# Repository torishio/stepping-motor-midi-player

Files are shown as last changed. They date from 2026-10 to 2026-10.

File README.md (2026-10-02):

# ステッピングモータでMIDIを再生できるやつ

stepping-motor-midi-player

USB MIDIで受け取った音を、ステッピングモーターに実際に鳴かせて音にするMIDIシンセサイザー。

**Languages:** [日本語](#日本語) | [English](#english) | [中文](#中文) | [한국어](#한국어)

---

## 日本語

### これは何?

STEPピンをMIDIノートの音程とぴったり同じ周波数でパカパカ切り替えると、ステッピングモーターがその音程で鳴いてくれる(singing stepperってやつ)。この現象を使って、A4988ドライバ+モーター1組を1音分の音源として、DAWやシーケンサーからMIDIで弾けるようにしたもの。各チャンネルにArduinoを1枚使うので、マスター機とかは無し。全部のArduinoが個別にUSB MIDI機器として認識される。

### 中身

- **`firmware/`** — Arduino(Pro Micro互換ボード)に書き込むスケッチ。
  - `stp_motr_channel_velocity/` → こっちが最終版。音程だけじゃなくベロシティ(強弱)もマイクロステップの粗さで表現できる。
  - `stp_motr_channel/` → ベロシティは見てない、シンプルな方。
  - 全チャンネル、同じスケッチを書き込むだけでOK。
- **`hardware/`** — 本番基板(2ch、100×50mm)関連を全部入れてある。
  - **`stp-motr-2ch-100x50-gerbers.zip`** → 製造用データ一式。KiCadすら開かずに、これをJLCPCBとかにそのままアップロードすれば発注できる。
  - `gerbers/` → 上のZIPを展開したやつ。個別に見たい時用。
  - `stp-motr-2ch-100x50.kicad_pro` / `.kicad_sch` / `.kicad_pcb` → 編集・確認したい人向けのKiCadデータ。自作フットプリント/シンボルも `stp_motr.pretty/` `stp_motr.kicad_sym` に同封してるので、これだけで開ける。
  - **`BOM.csv`** → 部品リスト。
  - **`digikey_order.csv`** → Digikeyにそのままインポートできる注文リスト。

### Arduino⇔A4988の配線

1チャンネル分の結線はこんな感じ。他のチャンネルも同じ。

Arduino Pro MicroとA4988の配線図

- D4→STEP、D5→DIR、D6→EN(常時LOWでドライバON)
- A0→MS1、A1→MS2、A2→MS3(マイクロステップの切り替え)
- VCC→VDD、GND→GND
- A4988側のRSTとSLPは自分同士でジャンパーするだけ、Arduino側のピンは要らない
- VMOT・コイル出力(1A/1B/2A/2B)・外部+12Vは図から省略(モーター/電源側の配線なので)

### 専用基板を使わず自分で組む場合

基板を起こさずブレッドボードとかで直結したい人向けに、電源・コンデンサ・モーターまで全部含めた回路図も置いてある。

DIY配線の全体回路図

- Arduino側のピンは上と同じ(D4/D5/D6/A0/A1/A2/VCC/GND)
- VMOT-GND間に100&micro;F(低周波の電流供給用)と100nF(PWMノイズ吸収用)を並列で入れる — これが無いとモーターがガキゴカ鳴りやすい
- 外部電源は使うモーターの定格電圧に合わせる(12V用モーターなら12V)
- A4988の1A/1B/2A/2Bをモーターの4本のコイル線に(どっちが1A/1Bかは実際に回してみて逆なら入れ替えればOK)
- Arduino GND・A4988のGND(2本とも)・コンデンサのGND足・外部電源のGND(-)は全部同じ1本のグラウンドとしてつなぐ
- A4988基板上のトリマ(Vref)で電流制限を調整するのを忘れずに。Pololu版(Rsense=0.1&Omega;)なら **Vref=0.8Vで1A制限** になる感じがちょうどいい。ここを合わせないとモーターが熱くなりすぎたり、逆に力が出なかったりする

### 用意するもの

- Arduino Pro Micro互換ボード(ATmega32U4, 5V/16MHz)をチャンネル数分
- Pololu A4988(ヒートシンク付きがおすすめ)をチャンネル数分
- NEMA17クラスのステッピングモーターをチャンネル数分
- 細かい部品は `hardware/BOM.csv` 見てください

### 基板の発注

1. `hardware/stp-motr-2ch-100x50-gerbers.zip` をダウンロード
2. JLCPCBとかPCBWayにそのままアップロード
3. 枚数と色選んで注文するだけ

### 部品の発注

- 全部 `hardware/BOM.csv` に書いてある
- Digikeyで買うなら `hardware/digikey_order.csv` をBOM Managerに突っ込むだけ

### ライセンス

MIT License。`LICENSE` 見てください。

---

## English

### What is this?

If you toggle an A4988's STEP pin at exactly the frequency of a MIDI note's pitch, the stepper motor it's driving will "sing" that pitch — people call this the "singing stepper" trick. This project turns one motor + A4988 pair into a single-voice synth channel, playable live from a DAW or sequencer over USB MIDI. One Arduino per channel, no master board — each one just shows up as its own USB MIDI device.

### What's in here

- **`firmware/`** — sketches for Pro Micro-compatible Arduinos.
  - `stp_motr_channel_velocity/` — the final one. Covers velocity too, not just pitch, by varying how coarse the microstepping is.
  - `stp_motr_channel/` — simpler, pitch-only version.
  - Just flash the same sketch to every channel's board, that's it.
- **`hardware/`** — everything for the actual board (2-channel, 100×50mm).
  - **`stp-motr-2ch-100x50-gerbers.zip`** — the manufacturing files. Upload this straight to JLCPCB or wherever, no need to even open KiCad.
  - `gerbers/` — same thing, already unzipped, if you want to poke at individual files.
  - `stp-motr-2ch-100x50.kicad_pro` / `.kicad_sch` / `.kicad_pcb` — the actual KiCad files if you want to look around or make changes. The custom footprints/symbols are bundled in `stp_motr.pretty/` and `stp_motr.kicad_sym` so it just opens.
  - **`BOM.csv`** — the parts list.
  - **`digikey_order.csv`** — drop this straight into Digikey's order tool.

### Arduino⇔A4988 wiring

Here's how one channel's wiring looks. Every other channel is identical.

Arduino Pro Micro to A4988 wiring diagram

- D4→STEP, D5→DIR, D6→EN (held LOW all the time to keep the driver on)
- A0→MS1, A1→MS2, A2→MS3 (microstep selection)
- VCC→VDD, GND→GND
- RST and SLP just jumper to each other on the A4988 — no Arduino pin needed
- VMOT, the coil outputs (1A/1B/2A/2B), and the external +12V are left out of the diagram since that's motor/power wiring, not Arduino wiring

### Building it without the custom board

If you'd rather wire this up on a breadboard or protoboard instead of ordering the PCB, here's the full circuit — power supply, decoupling caps, and motor included.

Full DIY schematic

- Arduino pins are the same as above (D4/D5/D6/A0/A1/A2/VCC/GND)
- Put a 100&micro;F (bulk current) and a 100nF (PWM noise) cap in parallel across VMOT-GND — skip these and the motor tends to buzz
- Match the external supply voltage to your motor's rating (12V motor → 12V supply)
- Wire A4988's 1A/1B/2A/2B to the motor's 4 coil leads (if it spins the wrong way or sounds off, just swap a pair)
- Don't forget to set the current limit via the A4988's onboard trimmer (Vref). For the Pololu board (Rsense = 0.1Ω), **Vref ≈ 0.8V gives roughly a 1A limit** — a good starting point. Skip this and the motor can overheat, or come out too weak.
- Arduino GND, both A4988 GND pins, the cap's ground leg, and the supply's GND/– all need to be the same single ground net

### What you'll need

- One Arduino Pro Micro-compatible board (ATmega32U4, 5V/16MHz) per channel
- One Pololu A4988 (heatsink recommended) per channel
- One NEMA17-class stepper per channel
- Everything else is in `hardware/BOM.csv`

### Ordering the board

1. Grab `hardware/stp-motr-2ch-100x50-gerbers.zip`
2. Upload it to JLCPCB, PCBWay, whatever you use
3. Pick a quantity/color and you're done

### Ordering parts

- It's all in `hardware/BOM.csv`
- Digikey people: just import `hardware/digikey_order.csv` into their BOM Manager

### License

MIT — see `LICENSE`.

---

## 中文

### 这是啥

如果让A4988的STEP引脚正好按某个MIDI音高对应的频率来回切换,它驱动的步进电机就会跟着"唱"出那个音高——大家管这叫"会唱歌的步进电机"。这个项目就是靠这招,把一个电机+A4988凑成一路单音音源,接上USB MIDI就能直接用DAW或音序器弹。每个声部一块Arduino,没有主控这种东西,每块板子自己就是一个独立的USB MIDI设备。

### 里面都有什么

- **`firmware/`** — 刷到Pro Micro兼容板上的程序。
  - `stp_motr_channel_velocity/` — 这是最终版,不只管音高,力度也靠微步细不细来表现。
  - `stp_motr_channel/` — 简化版,没管力度。
  - 每个声部的板子刷同一份程序就行。
- **`hardware/`** — 实际用的那块板子(2通道、100×50mm)的所有东西。
  - **`stp-motr-2ch-100x50-gerbers.zip`** — 生产用的文件,直接传到JLCPCB之类的厂家就能下单,KiCad都不用打开。
  - `gerbers/` — 同样的东西,解压好了,想单独看哪个文件就去这里。
  - `stp-motr-2ch-100x50.kicad_pro` / `.kicad_sch` / `.kicad_pcb` — 想看看电路或者改改的话,这是KiCad源文件。自定义的封装/符号都打包在 `stp_motr.pretty/` 和 `stp_motr.kicad_sym` 里了,打开就能用。
  - **`BOM.csv`** — 物料清单。
  - **`digikey_order.csv`** — 直接丢进Digikey的下单工具就行。

### Arduino与A4988的接线

一个声部的接线大概就是这样,其他声部都一样。

Arduino Pro Micro与A4988的接线图

- D4→STEP,D5→DIR,D6→EN(一直拉LOW让驱动器保持开启)
- A0→MS1,A1→MS2,A2→MS3(切换微步模式)
- VCC→VDD,GND→GND
- A4988上的RST和SLP自己接在一起就行,不用占Arduino的引脚
- VMOT、线圈输出(1A/1B/2A/2B)、外部+12V这些电机/电源侧的接线图里没画

### 不用专用板,自己动手接

想用面包板之类的东西直接接线、不打板的话,这里有张包含电源、滤波电容、电机的完整电路图。

DIY完整电路图

- Arduino这边的引脚跟上面一样(D4/D5/D6/A0/A1/A2/VCC/GND)
- VMOT-GND之间并联一个100&micro;F(供大电流用)和一个100nF(吸收PWM噪声用)——不加这俩电机容易嗡嗡响
- 外部电源电压要跟电机的额定电压匹配(12V电机就配12V电源)
- 把A4988的1A/1B/2A/2B接到电机的4根线圈引线上(转反了或者声音不对就随便换一对线试试)
- 别忘了用A4988板上的电位器调电流限制(Vref)。Pololu版(Rsense=0.1Ω)的话,**Vref=0.8V大概对应1A的限制**,这个值挺合适的。不调这个电机容易发热,或者没劲。
- Arduino的GND、A4988的两个GND引脚、电容的接地脚、电源的GND/-,这些都得接成同一个地

### 得准备点啥

- 每个声部一块Arduino Pro Micro兼容板(ATmega32U4,5V/16MHz)
- 每个声部一块Pololu A4988(建议带散热片)
- 每个声部一台NEMA17级步进电机
- 剩下的零件都列在 `hardware/BOM.csv` 里了

### 怎么下单做板子

1. 下载 `hardware/stp-motr-2ch-100x50-gerbers.zip`
2. 传到JLCPCB、PCBWay随便哪家
3. 选数量选颜色,完事

### 怎么买零件

- 都写在 `hardware/BOM.csv` 里
- 用Digikey的话,把 `hardware/digikey_order.csv` 直接导进它的BOM Manager就行

### 许可证

MIT,详见 `LICENSE`。

---

## 한국어

### 이게 뭐냐면

A4988의 STEP 핀을 MIDI 노트 음높이랑 정확히 같은 주파수로 토글해주면, 그 모터가 그 음으로 "노래"를 부른다. 다들 "노래하는 스테퍼"라고 부르는 그 트릭이다. 이걸로 모터+A4988 한 쌍을 음 하나짜리 채널로 만들어서, USB MIDI로 DAW나 시퀀서에서 바로 연주할 수 있게 한 거다. 채널마다 Arduino 한 장씩, 마스터 보드 같은 건 없고 각자 독립된 USB MIDI 장치로 인식된다.

### 들어있는 것

- **`firmware/`** — Pro Micro 호환 보드에 올리는 스케치.
  - `stp_motr_channel_velocity/` — 이게 최종판. 음높이뿐 아니라 벨로시티도 마이크로스텝 거칠기로 표현한다.
  - `stp_motr_channel/` — 벨로시티는 안 보는 단순 버전.
  - 모든 채널 보드에 같은 스케치 올리면 끝.
- **`hardware/`** — 실제 쓰는 보드(2채널, 100×50mm) 관련 전부.
  - **`stp-motr-2ch-100x50-gerbers.zip`** — 제작용 파일 묶음. KiCad 켤 필요도 없이 이걸 JLCPCB 같은 데 바로 올리면 주문된다.
  - `gerbers/` — 같은 걸 풀어놓은 것. 개별 파일 보고 싶을 때.
  - `stp-motr-2ch-100x50.kicad_pro` / `.kicad_sch` / `.kicad_pcb` — 회로 들여다보거나 고치고 싶으면 이 KiCad 파일들. 커스텀 풋프린트/심볼도 `stp_motr.pretty/`랑 `stp_motr.kicad_sym`에 같이 들어있어서 그냥 열면 된다.
  - **`BOM.csv`** — 부품 목록.
  - **`digikey_order.csv`** — Digikey BOM Manager에 그냥 넣으면 되는 주문 리스트.

### Arduino&#8596;A4988 배선

채널 하나의 배선은 이렇게 생겼다. 다른 채널도 다 똑같다.

Arduino Pro Micro와 A4988 배선도

- D4→STEP, D5→DIR, D6→EN (드라이버를 계속 켜두려고 항상 LOW)
- A0→MS1, A1→MS2, A2→MS3 (마이크로스텝 모드 선택)
- VCC→VDD, GND→GND
- A4988의 RST랑 SLP는 서로 점퍼만 해주면 됨, Arduino 핀은 필요 없음
- VMOT, 코일 출력(1A/1B/2A/2B), 외부 +12V는 모터/전원 쪽 배선이라 그림에서는 뺐음

### 전용 보드 없이 직접 조립하는 경우

PCB 주문 대신 브레드보드 같은 데 직접 배선하고 싶다면, 전원이랑 디커플링 커패시터, 모터까지 다 포함한 전체 회로도도 준비해놨다.

DIY 전체 회로도

- Arduino 핀은 위랑 똑같음(D4/D5/D6/A0/A1/A2/VCC/GND)
- VMOT-GND 사이에 100&micro;F(대전류용)랑 100nF(PWM 노이즈 제거용) 커패시터를 병렬로 — 이거 없으면 모터가 윙윙거리기 쉬움
- 외부 전원은 쓰는 모터 정격 전압에 맞추기(12V 모터면 12V 전원)
- A4988의 1A/1B/2A/2B를 모터 코일선 4개에 연결(방향이 반대거나 소리가 이상하면 한 쌍만 바꿔 끼워보면 됨)
- A4988 보드의 트리머(Vref)로 전류 제한 맞추는 것도 잊지 말기. Pololu 보드(Rsense=0.1Ω)라면 **Vref=0.8V가 대략 1A 제한**이라 딱 적당하다. 이거 안 맞추면 모터가 너무 뜨거워지거나 힘이 안 나온다.
- Arduino GND, A4988의 GND 두 개, 커패시터 접지 다리, 전원의 GND/- 는 전부 같은 그라운드 하나로 묶어야 함

### 필요한 것

- 채널당 Arduino Pro Micro 호환 보드(ATmega32U4, 5V/16MHz) 1개
- 채널당 Pololu A4988(방열판 추천) 1개
- 채널당 NEMA17급 스테핑 모터 1개
- 나머지는 `hardware/BOM.csv`에 다 있음

### 보드 주문하기

1. `hardware/stp-motr-2ch-100x50-gerbers.zip` 다운로드
2. JLCPCB든 PCBWay든 그대로 업로드
3. 수량/색상 고르고 끝

### 부품 주문하기

- `hardware/BOM.csv`에 다 적혀있음
- Digikey 쓴다면 `hardware/digikey_order.csv`를 BOM Manager에 그대로 넣으면 됨

### 라이선스

MIT. `LICENSE` 참고.

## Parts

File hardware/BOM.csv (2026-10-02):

Reference | Qty | Description | Value/Spec | Manufacturer | Manufacturer Part Number | Digikey Part Number | LCSC/JLCPCB Part Number | Package | Notes
U1;U2 | 2 | Arduino-compatible MCU module (ATmega32U4 USB MIDI) | Pro Micro 5V/16MHz | SparkFun Electronics | DEV-12640 | 1568-12640-ND | not on LCSC (module - buy via Digikey/SparkFun/Pololu) | Module (socketed - not soldered to PCB) | Plugs into U1A/U1B and U2A/U2B socket pairs.
U3;U4 | 2 | Stepper motor driver carrier board | A4988 w/ heatsink | Pololu | 1182 | 2183-1182-ND | not on LCSC (module - buy via Digikey/Pololu) | Module (socketed - not soldered to PCB) | Plugs into U3A/U3B and U4A/U4B socket pairs. Order the heatsink-included version.
U1A;U1B;U2A;U2B | 4 | Female pin socket strip (vertical THT) | 1x12 2.54mm | Sullins Connector Solutions | PPPC121LFBN-RC | S7045-ND | not confirmed on LCSC | THT vertical | Receives the Pro Micro module's pin rows. 2 per Arduino x 2 channels = 4. Confirmed real part via Digikey lookup.
U3A;U3B;U4A;U4B | 4 | Female pin socket strip (vertical THT) | 1x08 2.54mm | Sullins Connector Solutions | PPPC081LFBN-RC | S7041-ND | C3322325 | THT vertical | Receives the A4988 module's pin rows. 2 per A4988 x 2 channels = 4.
C1;C3 | 2 | Aluminum electrolytic capacitor radial THT | 100uF 25V 6.3mm dia 2.5mm pitch | Panasonic | EEU-FC1E101SH | P19638CT-ND | not confirmed on LCSC | THT radial | Motor supply (VMOT) bulk decoupling | one per channel. 2.5mm pitch and 6.3mm dia confirmed against our footprint.
C2;C4 | 2 | Ceramic disc capacitor THT non-polarized | 100nF 50V X7R (any lead-bendable disc cap works) | generic (very common part - any brand) | n/a - extremely generic | search "100nF ceramic disc capacitor THT" | search "100nF X7R THT" on LCSC | THT radial | High-frequency VMOT/GND decoupling right beside the bulk cap above -- damps PWM-chopping ring that the electrolytic's ESL can't follow (the "motor buzz/vibration" fix). Lead spacing is flexible/bendable like the electrolytic; 2.5mm or 5mm pitch parts both fit.
J1;J2 | 2 | Motor connector header (vertical THT) | JST-XH 4-pin | JST Sales America | B4B-XH-A(LF)(SN) | 455-2249-ND | C144395 | THT vertical | Mates with a JST-XH 4-pin housing (next 2 rows) crimped to the stepper motor's 4 coil wires.
(J1/J2 motor-side housing) | 2 | JST-XH 4-position housing | XHP-4 | JST | XHP-4 | 455-2267-ND | search LCSC for "JST XHP-4" | Crimp housing | Not on the PCB - terminates each motor's own wires. 1 per motor.
(J1/J2 motor-side crimp pins) | 8 (sold in 100-pack) | JST-XH crimp socket contact | SXH-001T-P0.6 | JST | SXH-001T-P0.6 | 455-1135-100-ND (100-pack minimum) | search LCSC for "JST SXH-001T-P0.6" | Crimp pin | 4 pins per motor x 2 motors = 8 needed; smallest Digikey pack is 100.
J3 | 1 | JST-XH 2-pin THT RIGHT-ANGLE header (shrouded) 2.5mm pitch | PWR STACK +12V/GND cable link | JST Sales America | S2B-XH-A(LF)(SN) | 455-2257-ND | search LCSC for "JST S2B-XH-A" | THT right-angle | Common/cheap connector, same XH family as J1/J2's motor connectors -- switched down from Molex Mini-Fit Jr (too pricey for what's otherwise a low-current link J4/KF301 already backs up). 3A/pin. RIGHT-ANGLE so the cable exits parallel to the board toward its bottom edge, not straight up.
(J3 cable - PREFERRED: ready-made) | 1 | Pre-crimped JST-XH 2-pin jumper cable, socket-to-socket, 22AWG, 254mm (10") | ASXHSXH22K254 | JST Sales America | ASXHSXH22K254 | 455-4223-ND | search LCSC for "JST XH 2 pin cable socket to socket" | Cable assembly | No crimping needed -- plugs straight onto J3's header on both boards. Shorter ASXHSXH22K203 (203mm/8") also exists if less slack is wanted. Skip the next 2 rows if using this.
(J3 cable - DIY alternative: housing) | 1 | JST-XH 2-position receptacle housing | XHP-2 | JST | XHP-2 | 455-2266-ND | C144401 | Crimp housing | Only needed if crimping your own cable instead of buying the ready-made one above. Contacts sold separately (next row).
(J3 cable - DIY alternative: crimp pins) | 2 | JST-XH crimp socket contact | SXH-001T-P0.6 | JST | SXH-001T-P0.6 | 455-1135-100-ND (100-pack minimum - same part already bought for J1/J2) | search LCSC for "JST SXH-001T-P0.6" | Crimp pin | Only needed for the DIY route. 1 pair (+12V/GND) per cable -- draw from the same 100-pack as J1/J2's motor crimp pins.
J4 | 1 | 2-position screw terminal block 5.08mm pitch 16A | PWR TERMINAL +12V/GND | Cixi Kefa Elec | KF301-5.0-2P | not available on Digikey (confirmed by lookup) | C474881 (also see KF128-5.08-2P-AA / C474952 for an explicit 5.08mm-pitch part) | THT | Wired power in/out for stacks taller than J3's pins can reach. Source via LCSC | not Digikey.
MH1;MH2;MH3;MH4 | 4 | M3 hex standoff female-female (confirmed real part) | M3 x 25mm (recommended) or M3 x 20mm | Keystone Electronics | 24408 (25mm brass) or 24487 (20mm stainless) | 36-24408-ND (25mm) / 36-24487-ND (20mm) | search LCSC for "M3 hex standoff 25mm female female" | Hardware (not placed on PCB) | 25mm gives a few mm of clearance past the A4988+heatsink height (~20mm); use 20mm only if stack height is tight. Both confirmed M3/female-female on Digikey. 3.2mm mounting holes clear M3.
(fasteners for MH1-4) | 8 | M3 pan-head machine screw | M3 x 6mm | generic | n/a | n/a | n/a | Hardware | 2 screws per standoff x 4 standoffs = 8.
(PCB fab) | 1 | Bare PCB | 100mm x 50mm 2-layer FR4 | JLCPCB | n/a | n/a | n/a | PCB | Order directly from JLCPCB using Gerbers from stp-motr-2ch-100x50.kicad_pcb - not a BOM line item.

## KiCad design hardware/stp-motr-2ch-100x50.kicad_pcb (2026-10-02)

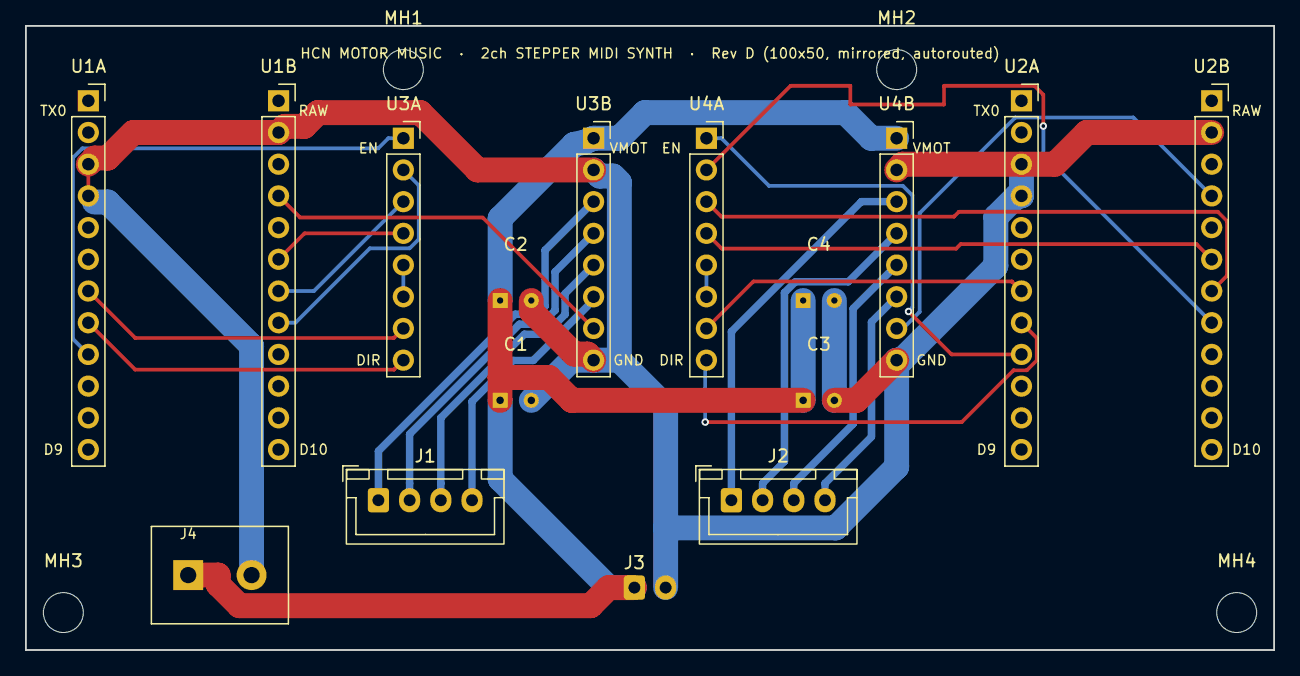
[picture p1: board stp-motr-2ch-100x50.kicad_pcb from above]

Board: 2 copper layers, 100.0 x 50.0 mm, 20 parts (0 on the bottom side), 26 nets.

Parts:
C1, C3: 100uF 25V THT; CP_Radial_D6.3mm_P2.50mm
C2, C4: 100nF ceramic; C_Disc_D4mm_P2.50mm
J1: Motor 1; JST_XH_B4B-XH-A_1x04_P2.50mm_Vertical
J2: Motor 2; JST_XH_B4B-XH-A_1x04_P2.50mm_Vertical
J3: PWR STACK; JST_XH_B2B-XH-AR_1x02_P2.50mm_RightAngle
J4: PWR TERMINAL; KF301-2P_5.08mm
MH1, MH2, MH3, MH4: MountingHole_3.2mm_M3
U1A: Pro Micro 1L; PinSocket_1x12_P2.54mm_Vertical
U1B: Pro Micro 1R; PinSocket_1x12_P2.54mm_Vertical
U2A: Pro Micro 2L; PinSocket_1x12_P2.54mm_Vertical
U2B: Pro Micro 2R; PinSocket_1x12_P2.54mm_Vertical
U3A: A4988 1 CTRL; PinSocket_1x08_P2.54mm_Vertical
U3B: A4988 1 PWR; PinSocket_1x08_P2.54mm_Vertical
U4A: A4988 2 CTRL; PinSocket_1x08_P2.54mm_Vertical
U4B: A4988 2 PWR; PinSocket_1x08_P2.54mm_Vertical

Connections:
+12V: C1.1, C2.1, C3.1, C4.1, J3.1, J4.1, U3B.1, U4B.1
B1_VCC: U1B.4, U3B.7
B2_VCC: U2B.4, U4B.7
GND: C1.2, C2.2, C3.2, C4.2, J3.2, J4.2, U1A.3, U1A.4, U1B.2, U2A.3, U2A.4, U2B.2, U3B.2, U3B.8, U4B.2, U4B.8
M1_1A: J1.3, U3B.5
M1_1B: J1.4, U3B.6
M1_2A: J1.2, U3B.4
M1_2B: J1.1, U3B.3
M2_1A: J2.3, U4B.5
M2_1B: J2.4, U4B.6
M2_2A: J2.2, U4B.4
M2_2B: J2.1, U4B.3
S1_DIR: U1A.8, U3A.8
S1_EN: U1A.9, U3A.1
S1_MS1: U1B.8, U3A.2
S1_MS2: U1B.7, U3A.3
S1_MS3: U1B.6, U3A.4
S1_RST_SLP: U3A.5, U3A.6
S1_STEP: U1A.7, U3A.7
S2_DIR: U2A.8, U4A.8
S2_EN: U2A.9, U4A.1
S2_MS1: U2B.8, U4A.2
S2_MS2: U2B.7, U4A.3
S2_MS3: U2B.6, U4A.4
S2_RST_SLP: U4A.5, U4A.6
S2_STEP: U2A.7, U4A.7

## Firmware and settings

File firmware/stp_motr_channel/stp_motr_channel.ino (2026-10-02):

/*
 * stp_motr_channel.ino
 *
 * Copyright (c) 2026 HCN TORISHIO
 * Released under the MIT License (see LICENSE in the repository root).
 *
 * Firmware for ONE channel of the 6-axis stepper MIDI player.
 * Flash the SAME sketch onto all 6 boards -- there is no master, no
 * SoftwareSerial link. Each Arduino Micro enumerates on its own as a
 * class-compliant USB MIDI device (via the MIDIUSB library) and plays
 * whatever notes it receives by "singing" them on its own A4988-driven
 * stepper motor.
 *
 * ------------------------------------------------------------------
 * REQUIRED Arduino IDE SETUP (read this before flashing):
 * ------------------------------------------------------------------
 *   1. Library: install "MIDIUSB" (by Gary Grewal) via
 *      Sketch > Include Library > Manage Libraries.
 *   2. Board: this board is a Pro Micro-COMPATIBLE clone, not a
 *      genuine Arduino Micro -- it has no D11/D12/D13, and its
 *      silkscreen A0-A3 / D14-D16 are wired differently than the
 *      real Arduino Micro's A0-A5. Selecting "Arduino Micro" in the
 *      Boards menu will map these pin names to the WRONG physical
 *      pins. Select a Pro Micro (ATmega32u4, 5V/16MHz) board profile
 *      instead (e.g. SparkFun AVR Boards > SparkFun Pro Micro,
 *      installable via Boards Manager if not already present).
 *   3. Wiring reference: see hardware/stp-motr-schematic -- STEP=D4,
 *      DIR=D5, ENABLE=D6, MS1=A0, MS2=A1, MS3=A2.
 * ------------------------------------------------------------------
 *
 * Pitch mechanism: the STEP pin is toggled at exactly the target
 * note's frequency (the classic "singing stepper" trick -- each
 * electrical step edge is an audible click, a stream of them at f Hz
 * is heard as a tone at f Hz). Timer1 (hardware CTC interrupt) drives
 * the pulses so USB polling in loop() never causes timing jitter.
 *
 * Stall avoidance: the MECHANICAL step rate (STEP pin frequency
 * divided by the microstep multiplier) is what can actually stall the
 * motor, not the electrical pulse rate itself. selectStepMode() picks
 * the coarsest microstep mode (best torque, loudest tone) for which
 * mechanical_rate = frequency / multiplier stays at or below
 * MAX_STEP_RATE, and only goes finer as pitch rises. Tune
 * MAX_STEP_RATE on real hardware: start low (400), and raise it
 * (600, 800, ...) while listening/watching for skipped steps.
 *
 * Debug output: open the Arduino IDE's Serial Monitor (115200 baud) to see
 * which note is currently sounding, its frequency, chosen microstep mode,
 * and mechanical step rate, updated every time a note starts/stops/changes.
 * This is a separate USB Serial port from the MIDI connection, so it works
 * whether or not anything is listening -- no need to disconnect from a DAW.
 */

#include <MIDIUSB.h>
#include <math.h>
#include <string.h>
#include <stdio.h>

// ---- Pin map (Pro Micro-compatible silkscreen labels) --------------------
const uint8_t PIN_STEP = 4;
const uint8_t PIN_DIR = 5;
const uint8_t PIN_ENABLE = 6;
const uint8_t PIN_MS1 = A0;
const uint8_t PIN_MS2 = A1;
const uint8_t PIN_MS3 = A2;

// ---- Motor / driver tuning -------------------------------------------------
#define STEPS_PER_REV 200      // full steps/rev -- check the motor's datasheet
#define MAX_STEP_RATE 400.0f   // mechanical (full-step-equivalent) steps/sec
                                // ceiling. Start here, raise gradually (see above).

// A4988 microstep table: {MS1, MS2, MS3, multiplier}. Ordered coarsest first
// so selectStepMode() can stop at the first entry that keeps the mechanical
// rate under MAX_STEP_RATE.
struct StepMode {
  uint8_t ms1, ms2, ms3;
  uint8_t multiplier;
};
const StepMode STEP_MODES[] = {
  {0, 0, 0, 1},   // full step
  {1, 0, 0, 2},   // half step
  {0, 1, 0, 4},   // quarter step
  {1, 1, 0, 8},   // eighth step
  {1, 1, 1, 16},  // sixteenth step
};
const uint8_t N_STEP_MODES = sizeof(STEP_MODES) / sizeof(STEP_MODES[0]);

// ---- MIDI channel filter ---------------------------------------------------
// 0 = respond to notes on any channel (default -- each board is its own USB
// device, so the DAW/OS routes to it by port, not by channel). Set to 1-16
// to make this board ignore everything except that channel.
#define MIDI_CHANNEL_FILTER 0

// ---- Simple monophonic note stack (last-note priority with fallback) ------
#define NOTE_STACK_SIZE 8
uint8_t noteStack[NOTE_STACK_SIZE];
uint8_t noteStackLen = 0;

void pushNote(uint8_t note) {
  for (uint8_t i = 0; i < noteStackLen; i++) {
    if (noteStack[i] == note) return;  // already held
  }
  if (noteStackLen < NOTE_STACK_SIZE) {
    noteStack[noteStackLen++] = note;
  } else {
    // stack full: drop the oldest, shift up, append newest
    memmove(noteStack, noteStack + 1, NOTE_STACK_SIZE - 1);
    noteStack[NOTE_STACK_SIZE - 1] = note;
  }
}

void removeNote(uint8_t note) {
  for (uint8_t i = 0; i < noteStackLen; i++) {
    if (noteStack[i] == note) {
      memmove(noteStack + i, noteStack + i + 1, noteStackLen - i - 1);
      noteStackLen--;
      return;
    }
  }
}

// ---- Step mode selection ---------------------------------------------------
void applyStepMode(const StepMode &m) {
  digitalWrite(PIN_MS1, m.ms1);
  digitalWrite(PIN_MS2, m.ms2);
  digitalWrite(PIN_MS3, m.ms3);
}

const StepMode &selectStepMode(float freqHz) {
  for (uint8_t i = 0; i < N_STEP_MODES; i++) {
    float mechanicalRate = freqHz / STEP_MODES[i].multiplier;
    if (mechanicalRate <= MAX_STEP_RATE) {
      return STEP_MODES[i];
    }
  }
  return STEP_MODES[N_STEP_MODES - 1];  // finest available -- best effort
}

// ---- Timer1: hardware-clocked STEP pulse generator -------------------------
// CTC mode, toggles PIN_STEP on every compare match at exactly `freqHz`.
volatile bool stepPinState = false;

void stopStepping() {
  TIMSK1 &= ~(1 << OCIE1A);
  digitalWrite(PIN_STEP, LOW);
  stepPinState = false;
}

void setStepFrequency(float freqHz) {
  if (freqHz <= 0.5f) {
    stopStepping();
    return;
  }

  const uint16_t prescalers[] = {1, 8, 64, 256, 1024};
  const uint8_t csBits[] = {
    (1 << CS10),
    (1 << CS11),
    (1 << CS11) | (1 << CS10),
    (1 << CS12),
    (1 << CS12) | (1 << CS10),
  };

  for (uint8_t i = 0; i < 5; i++) {
    // toggling twice per cycle -> compare-match interrupt fires at 2x freqHz
    uint32_t ocr = (uint32_t)(F_CPU / (2UL * prescalers[i] * freqHz)) - 1;
    if (ocr <= 65535UL) {
      noInterrupts();
      TCCR1A = 0;
      TCCR1B = (1 << WGM12) | csBits[i];  // CTC, TOP = OCR1A
      OCR1A = (uint16_t)ocr;
      TCNT1 = 0;
      TIMSK1 |= (1 << OCIE1A);
      interrupts();
      return;
    }
  }
  // frequency too low even at the largest prescaler -- stop rather than
  // wrap around into a bogus (huge) OCR1A value.
  stopStepping();
}

ISR(TIMER1_COMPA_vect) {
  // digitalWrite() here is simple and readable; if the very highest MIDI
  // notes sound unstable, this is the place to switch to a direct port
  // write (e.g. PORTD ^= (1 << PD4) for D4) to cut the per-interrupt cost.
  stepPinState = !stepPinState;
  digitalWrite(PIN_STEP, stepPinState ? HIGH : LOW);
}

// ---- Note -> frequency ------------------------------------------------------
float noteToFrequency(uint8_t note) {
  return 440.0f * pow(2.0f, (note - 69) / 12.0f);
}

// ---- Note -> human-readable name (e.g. "A4", "C#5") for the debug log ------
void noteName(uint8_t note, char *out) {
  static const char *NAMES[12] = {"C", "C#", "D", "D#", "E", "F",
                                   "F#", "G", "G#", "A", "A#", "B"};
  int8_t octave = (int8_t)(note / 12) - 1;
  const char *name = NAMES[note % 12];
  sprintf(out, "%s%d", name, octave);
}

// ---- Debug output: what's currently sounding, and how ----------------------
// Open the Arduino IDE's Serial Monitor (115200 baud) to watch this. USB MIDI
// and USB Serial run over the same cable at the same time (composite USB
// device), so this works alongside a DAW/synth without unplugging anything.
void logVoice(bool playing, uint8_t note, float freq, const StepMode &mode) {
  if (!playing) {
    Serial.println(F("[voice] off"));
    return;
  }
  char name[5];
  noteName(note, name);
  float mechanicalRate = freq / mode.multiplier;
  Serial.print(F("[voice] note="));
  Serial.print(note);
  Serial.print(' ');
  Serial.print(name);
  Serial.print(F("  freq="));
  Serial.print(freq, 1);
  Serial.print(F("Hz  microstep=1/"));
  Serial.print(mode.multiplier);
  Serial.print(F("  mech_rate="));
  Serial.print(mechanicalRate, 1);
  Serial.println(F("steps/s"));
}

// ---- Apply whatever note is now on top of the stack -------------------------
void updateVoice() {
  if (noteStackLen == 0) {
    stopStepping();
    logVoice(false, 0, 0, STEP_MODES[0]);
    return;
  }
  uint8_t note = noteStack[noteStackLen - 1];
  float freq = noteToFrequency(note);
  const StepMode &mode = selectStepMode(freq);
  applyStepMode(mode);
  setStepFrequency(freq);
  logVoice(true, note, freq, mode);
}

// ---- MIDI handling -----------------------------------------------------------
void handleNoteOn(uint8_t channel, uint8_t note, uint8_t velocity) {
#if MIDI_CHANNEL_FILTER != 0
  if (channel != (MIDI_CHANNEL_FILTER - 1)) return;
#endif
  if (velocity == 0) {
    removeNote(note);  // MIDI convention: NoteOn vel=0 == NoteOff
  } else {
    pushNote(note);
  }
  updateVoice();
}

void handleNoteOff(uint8_t channel, uint8_t note) {
#if MIDI_CHANNEL_FILTER != 0
  if (channel != (MIDI_CHANNEL_FILTER - 1)) return;
#endif
  removeNote(note);
  updateVoice();
}

void pollMidi() {
  midiEventPacket_t rx;
  do {
    rx = MidiUSB.read();
    switch (rx.header) {
      case 0x9:  // Note On
        {
          uint8_t status = rx.byte1;
          uint8_t channel = status & 0x0F;
          uint8_t note = rx.byte2;
          uint8_t velocity = rx.byte3;
          handleNoteOn(channel, note, velocity);
        }
        break;
      case 0x8:  // Note Off
        {
          uint8_t status = rx.byte1;
          uint8_t channel = status & 0x0F;
          uint8_t note = rx.byte2;
          handleNoteOff(channel, note);
        }
        break;
      default:
        break;
    }
  } while (rx.header != 0);
}

// ---- Setup / loop -------------------------------------------------------------
void setup() {
  Serial.begin(115200);  // debug log only -- MIDI itself goes over MIDIUSB,
                          // not this port, so nothing needs the DAW/Serial
                          // Monitor to be listening for notes to work.

  pinMode(PIN_STEP, OUTPUT);
  pinMode(PIN_DIR, OUTPUT);
  pinMode(PIN_ENABLE, OUTPUT);
  pinMode(PIN_MS1, OUTPUT);
  pinMode(PIN_MS2, OUTPUT);
  pinMode(PIN_MS3, OUTPUT);

  digitalWrite(PIN_ENABLE, LOW);  // A4988 ENABLE is active-low; left enabled
                                  // permanently (see schematic design notes)
  digitalWrite(PIN_DIR, HIGH);    // continuous one-direction spin -- this is
                                  // a tone generator, not a positioner
  digitalWrite(PIN_STEP, LOW);
  applyStepMode(STEP_MODES[0]);
}

void loop() {
  pollMidi();
}

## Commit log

2026-10-02 Initial commit: firmware and production board data
    Arduino firmware (pitch-only and velocity-sensitive variants) and the
    production 2-channel, 100x50mm board: KiCad source, fab-ready Gerbers,
    and a bill of materials with a Digikey order sheet.
    [BOM.csv, digikey_order.csv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]
2026-10-02 Add Arduino-A4988 wiring diagram, reference it in all 4 README languages
2026-10-02 Add full DIY schematic (power, caps, motor) for people not using the PCB
2026-10-02 README: add A4988 Vref current-limit tip (~0.8V for 1A) to all languages
